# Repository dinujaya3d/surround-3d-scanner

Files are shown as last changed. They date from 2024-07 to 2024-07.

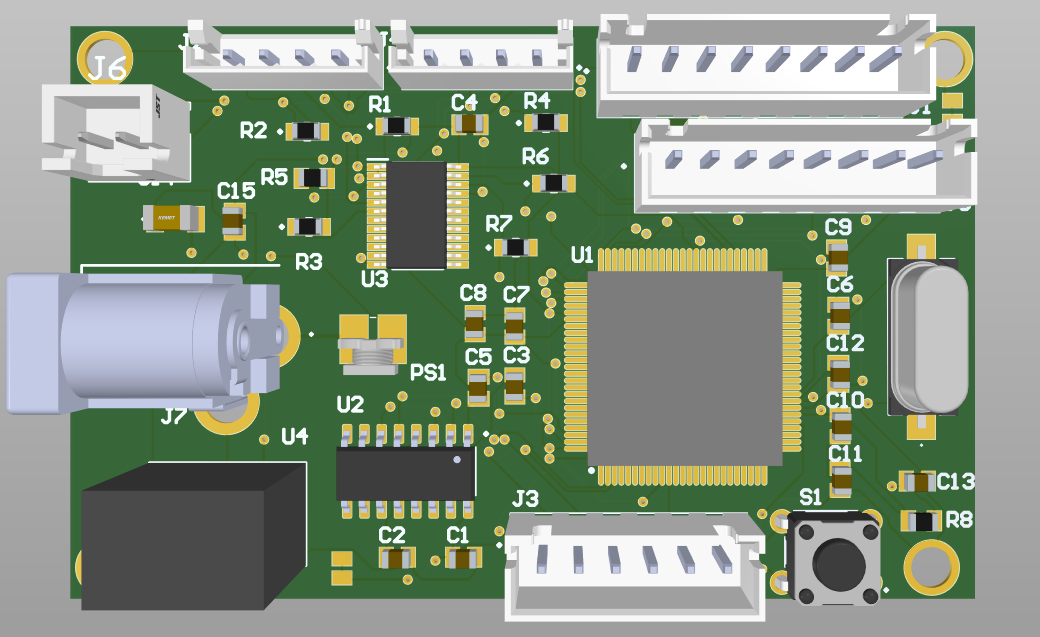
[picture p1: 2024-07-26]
PCB design/3D view.png

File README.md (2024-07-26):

# 3D-Mapper 
* 3D-Mapper is a 3D plotting device made for short-range object detection powered by [ATmega 2560](https://github.com/LasithaAmarasinghe/3D-Mapper/blob/main/data%20sheets/ATMEGA2560.PDF).
* This is developed for the semester 4 project under EN 2160: Electronic Design Realization.



## Working Principle 

* This device measures distances to objects using two Time-of-Flight (TOF) sensors, which are rotated by two stepper motors to cover the entire 3D environment.
* The distance values are saved in (r, theta, alpha) coordinates and then converted to (x, y, z) coordinates.
* Using the [PyVista](https://github.com/pyvista) library in Python, a 3D point cloud is generated from these cartesian coordinates. 
* A tetrahedral mesh is created by performing [3D Delaunay triangulation](https://github.com/LasithaAmarasinghe/3D-Mapper/blob/main/3D%20Delaunay%20Triangulation.pdf) on the point cloud.
* Then the outer surface of this tetrahedral mesh is extracted to form a surface mesh.

## Why "3D-Mapper"?

* Precision in Short-Range Mapping
* Comprehensive Coverage
* Cost-Effective
* Scalability and Customization
* Versatility Across Industries

## Areas of Opportunity

* Emerging Technology Integration - Enhance capabilities with AI and machine learning.
* Market Expansion - Adapt for use in virtual reality (VR) & augmented reality (AR) to access new and growing markets.
* Data Analytics Enhancement - Develop advanced software for better data analysis and visualization, adding value and creating new revenue streams.

## Hardware Specifications

* [ATmega2560](https://github.com/LasithaAmarasinghe/3D-Mapper/blob/main/data%20sheets/ATMEGA2560.PDF)
* [CH340C USB to Serial Chip](https://github.com/LasithaAmarasinghe/3D-Mapper/blob/main/data%20sheets/CH340C%20USB%20to%20serial%20chip.PDF)
* [I2C Multiplexer](https://github.com/LasithaAmarasinghe/3D-Mapper/blob/main/data%20sheets/tca9548a%20I2C%20multiplexer.pdf)
* [Nema 17 Stepper Motors](https://github.com/LasithaAmarasinghe/3D-Mapper/blob/main/data%20sheets/NEMA17%20Stepper%20Motor.PDF)
* [Micro Step Motor Drivers](https://github.com/LasithaAmarasinghe/3D-Mapper/blob/main/data%20sheets/TB6600-Micro%20Step%20Stepper-Motor-Driver.pdf)
* [TOF Sensors](https://github.com/LasithaAmarasinghe/3D-Mapper/blob/main/data%20sheets/TOF.png)
* [12V to 5V Buck Converter](https://github.com/LasithaAmarasinghe/3D-Mapper/blob/main/data%20sheets/R_78CK_0_5-DC_DC%20Converter.pdf)

## Software Specifications

* Arduino IDE
* Solid Works
* Altium
* Python 











## PCB Design



## PCB 

PCB

## Solidworks Design

solidworks
Interior Design
Side view

## Team

team

## For More Information  

- **[Design Document](Design_Document.pdf)**
- **[Design Methodology Report](Design_Methodology_Report.pdf)**

## License
 
 * This project is licensed under the MIT License. See the [LICENSE](MIT-LICENSE.txt) file for details.

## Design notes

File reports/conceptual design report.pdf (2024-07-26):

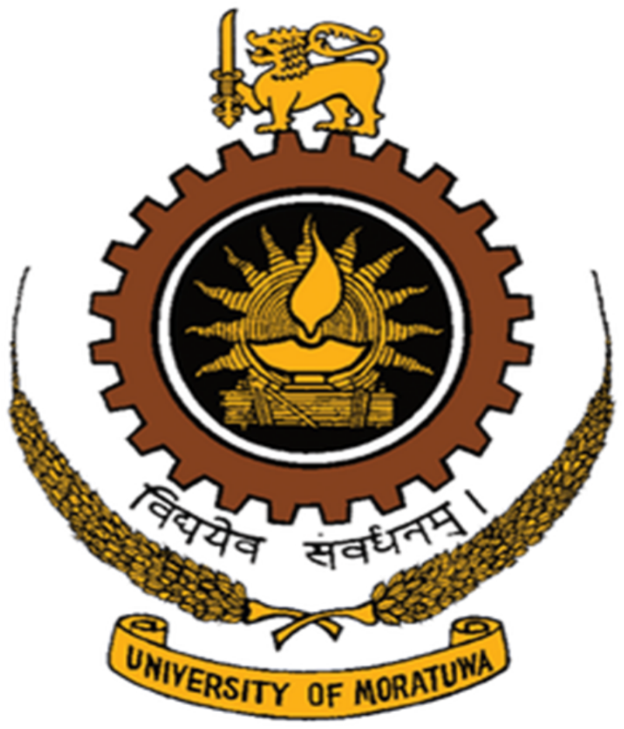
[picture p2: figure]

# Department of Electronic & Telecommunication

Engineering,
University of Moratuwa, Sri Lanka.

# 3D Mapping Device for Object Tracking Conceptual Design Report - Group B

## Submitted By:

210728C Wijewickrama W.K.D.D.D. 210031H Amarasinghe A.A.W.L.R.

Submitted in partial fulfillment of the requirements for the module

# EN 2160 : Electronic Design Realization

7th March 2024

EN2160 | Conceptual Design Report : Group B

## Contents

1 Conceptual Designs and Functional Block Diagrams | 2
2 Comparison of Designs | 8
3 Evaluation Criteria | 9

1

## 1 Conceptual Designs and Functional Block Diagrams

### 1.1 Design 1

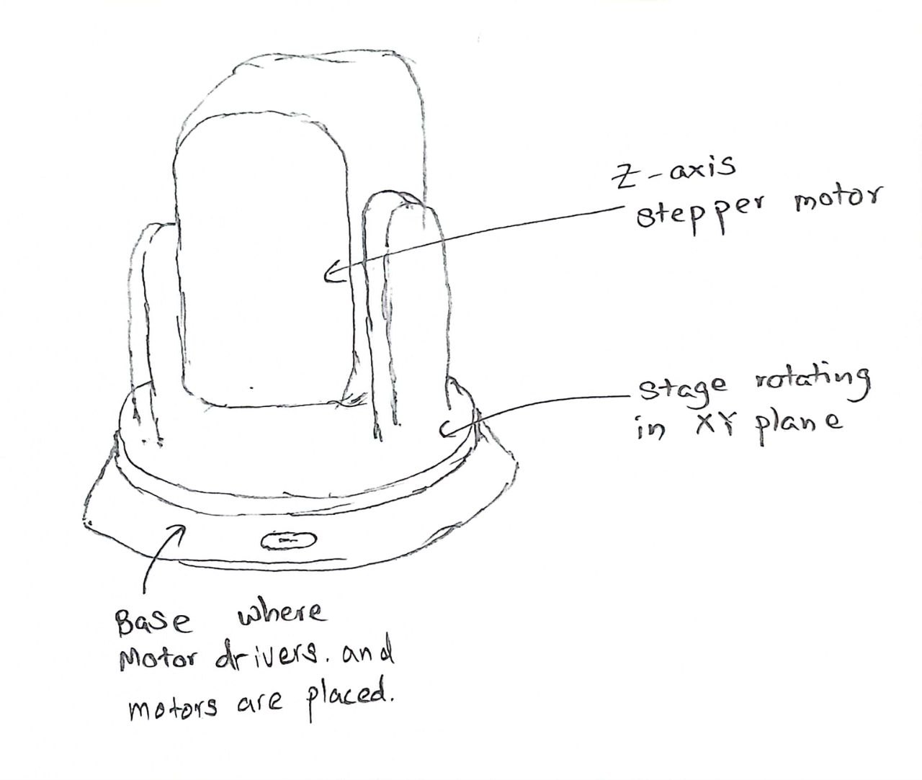
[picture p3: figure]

Figure 1: Design 1: Stage and 2 Steppers

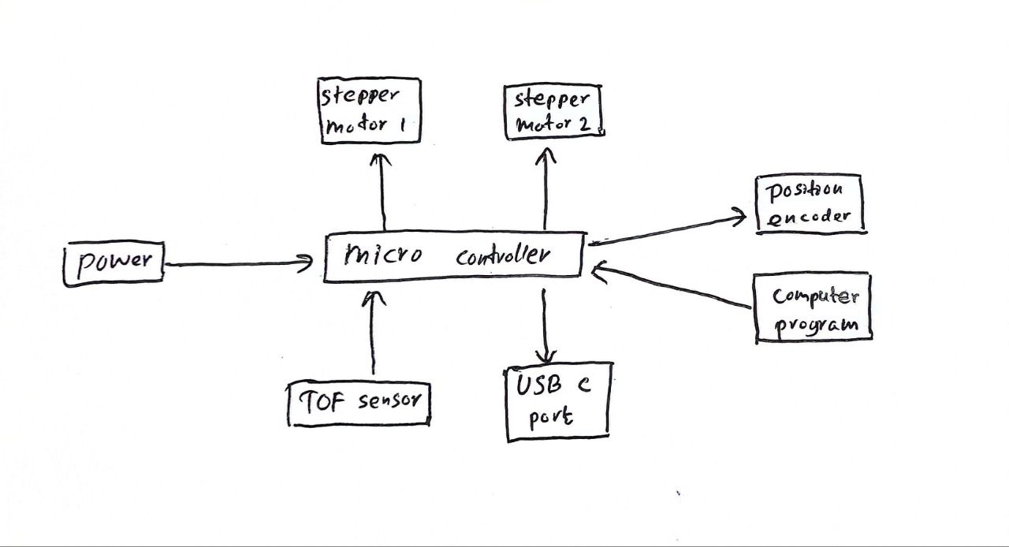
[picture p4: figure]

Figure 2: Block Diagram 1

2

### 1.1.1 Overview

This innovative design merges the Time of Flight (ToF) sensor concept with the precision control of stepper motors to create a dynamic two Degrees of Freedom (2-DoF) rotational system. It incorporates two stepper motors, with one strategically positioned to govern movement along the xy plane within the base, while the other orchestrates stage rotation using z-axis angles obtained from the ToF sensor. This arrangement ensures meticulous measurement of r, θ, and α values for each reading, thereby enhancing system accuracy.

### 1.1.2 Operation

- Integration of ToF sensor technology with stepper motors for precise control.
- Two stepper motors utilized: one for xy plane movement and another for stage rotation.
- ToF sensor provides z-axis angles for enhanced control and accuracy.
- Enables meticulous measurement of r, θ, and α values for each reading.
- Data transmission facilitated through USB Type-C port, ensuring seamless connectivity and efficient data transfer.
- Advanced processing techniques applied on the computer to convert data into a comprehensive point cloud representation.
- Sophisticated image detection algorithms employed for in-depth analysis and interpretation.

### 1.1.3 Advantages

- This design offers precise control over rotational movements.
- Streamlines data processing and analysis, making it a versatile solution for diverse applications requiring precise spatial measurements and analysis.

### 1.1.4 Challenges

However, there are some challenges associated with this design:

- Mechanical Complexity: Incorporating two stepper motors and a ToF sensor system adds mechanical complexity, requiring careful calibration and maintenance to ensure reliable operation.
- Computational Requirements: Advanced processing techniques and image detection algorithms may demand significant computational power, posing challenges in terms of hardware requirements and computational efficiency.

3

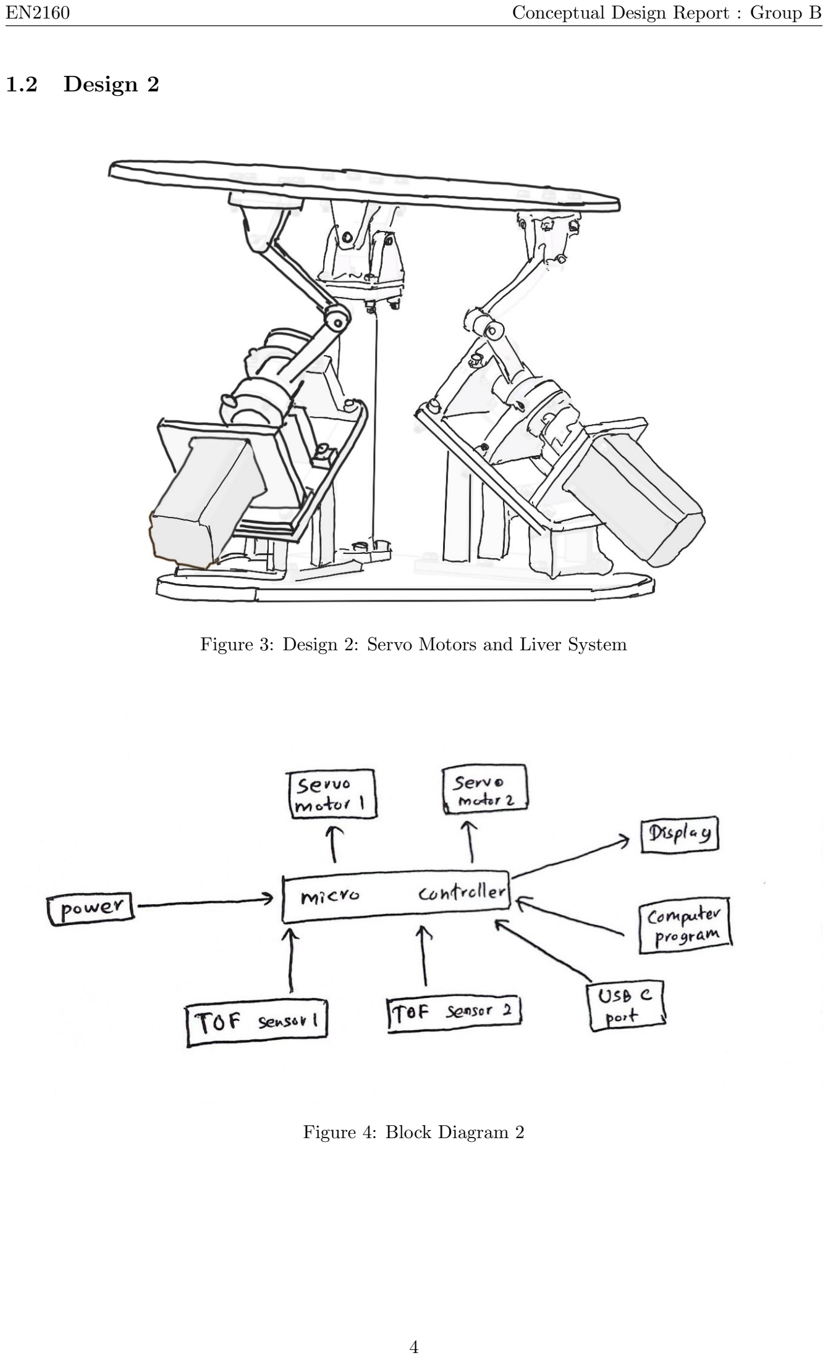
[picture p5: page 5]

### 1.2 Design 2

Figure 3: Design 2: Servo Motors and Liver System

Figure 4: Block Diagram 2

4

### 1.2.1 Overview:

Design 1 utilizes a basement housing two time-of-flight (ToF) sensors, each equipped with servo motors for precise adjustment. The servo motors enable the rotation and tilting of the basement to capture surrounding data from various angles.
Components:
1. Basement Housing: The basement serves as the platform for mounting the ToF sensors and servo motors. It is designed to be adjustable in both rotation and tilt angles.
2. ToF Sensors: Two ToF sensors are mounted on the basement to capture depth information. These sensors emit infrared light pulses and measure the time taken for the pulses to reflect back, allowing for accurate distance calculations.
3. Servo Motors: The servo motors are responsible for adjusting the orientation of the basement. They provide precise control over the rotation and tilt angles, allowing for comprehensive coverage of the surrounding environment.

### 1.2.2 Operation:

- Rotation Control: One servo motor is dedicated to controlling the rotation of the basement. By rotating the basement, the sensors can scan the surroundings horizontally, providing a panoramic view of the scene.
- Tilt Control: The second servo motor adjusts the tilt angle of the basement. This enables the sensors to capture data from different elevations, facilitating a more detailed representation of the environment.

### 1.2.3 Advantages:

- Precise Control: The servo motors offer precise adjustment capabilities, allowing for finetuning of the sensor positions to capture accurate data.
- Comprehensive Coverage: By rotating and tilting the basement, the design ensures thorough coverage of the surrounding environment, resulting in more comprehensive 3D scans.

### 1.2.4 Challenges:

- Mechanical Complexity: The incorporation of servo motors adds mechanical complexity to the design, requiring careful calibration and maintenance to ensure reliable operation.
- Power Consumption: Servo motors may consume significant power, which could impact the overall energy efficiency of the system.

5

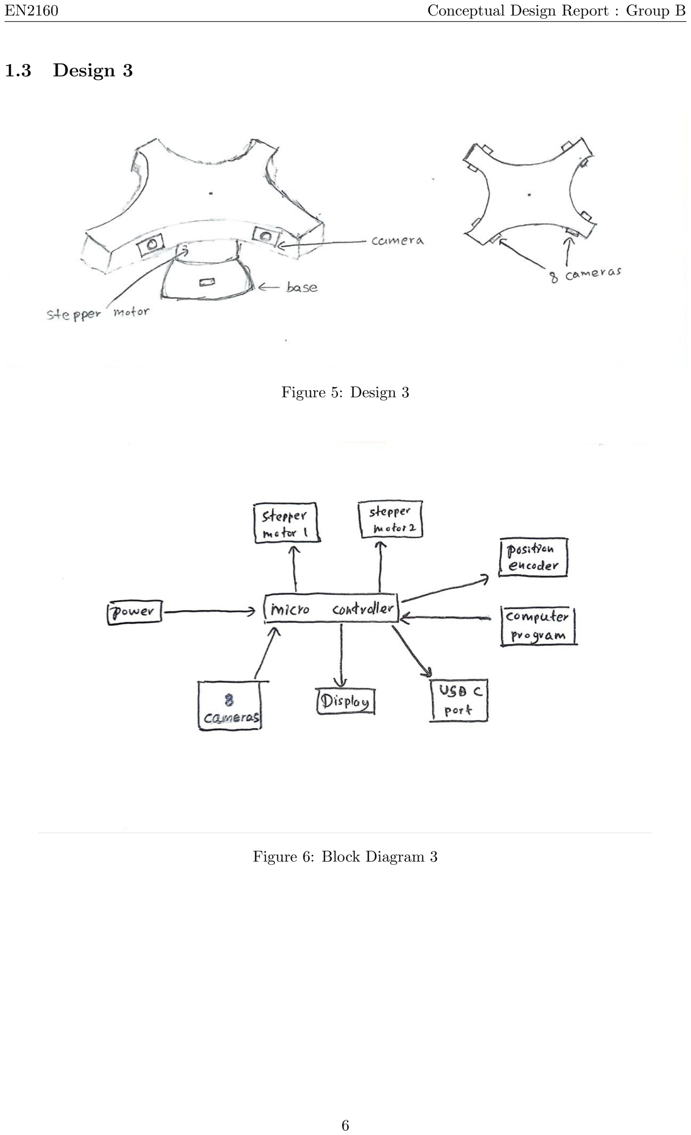
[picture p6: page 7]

### 1.3 Design 3

Figure 5: Design 3

Figure 6: Block Diagram 3

6

### 1.3.1 Overview

This cutting-edge design leverages image processing technology, employing a sophisticated array of eight cameras strategically positioned to capture comprehensive visual data. Among these cameras, a subset is dedicated to recording videos from one side, utilizing precise angles and calibration to facilitate the generation of detailed 3D objects through advanced image processing concepts. The collective data captured by the eight cameras is then meticulously processed through Convolutional Neural Networks (CNNs), enabling the generation of accurate 3D mappings and point clouds.

- Utilization of eight cameras for comprehensive visual data capture.
- Subset of cameras dedicated to video recording from one side.
- Angled and calibrated cameras facilitate detailed 3D object generation.
- Data from the camera array processed through Convolutional Neural Networks (CNNs).
- CNNs enable accurate generation of 3D mappings and point clouds.

### 1.3.2 Challenges

However, a notable challenge lies in the associated costs and computational requirements. The complexity of processing data from multiple cameras in real-time demands significant computational power, which may pose challenges in terms of both hardware affordability and computational efficiency.

### 1.3.3 Advantages

The advantages of this design include:

- High-Quality Data: The use of eight cameras allows for comprehensive visual data capture, resulting in high-quality 3D reconstructions.
- Detailed 3D Objects: The subset of cameras dedicated to video recording from one side, along with precise angles and calibration, facilitates the generation of detailed 3D objects.
- Accurate Processing: The utilization of Convolutional Neural Networks (CNNs) ensures accurate processing of the captured data, leading to precise 3D mappings and point clouds.

### 1.3.4 Significance

This design represents a powerful fusion of cutting-edge imaging technology and advanced computational algorithms, promising high-fidelity 3D reconstructions and data analysis. Despite the challenges posed by cost and computational demands, the potential applications of such a system in various fields such as robotics, augmented reality, and medical imaging underscore its significance and potential impact.

7

## 2 Comparison of Designs

Table 1: Comparison of Designs

Criteria | Design 1 Design 2 Design 3

## Features

## Enclosure Design Criteria Comparison

## Functional Block Design Criteria Comparison

Total | 120 100 105
TOF sensor | ✓ | ✓
cameras | | | ✓
servo motors | | ✓
stepper motors | ✓ | | ✓
display | | ✓ | ✓
position encoder | ✓ | | ✓
Functionality | 8 | 7 | 8
Aesthetics | 9 | 8 | 6
Heat Dissipation | 9 | 8 | 9
Assembly and Serviceability | 8 | 7 | 6
Ergonomics | 9 | 9 | 7
Simplicity | 9 | 5 | 7
Durability | 9 | 7 | 6
Functionality | 8 | 7 | 8
User Experience | 9 | 8 | 7
Manufacturing Feasibility | 9 | 6 | 9
Cost Efficiency | 8 | 6 | 9
Performance | 8 | 7 | 8
Future Proofing | 9 | 8 | 9
Power | 8 | 7 | 6

8

## 3 Evaluation Criteria

### 3.1 Enclosure Design Criteria:

1. Functionality: How well the design supports the main functionalities?
2. Aesthetics: How eye-catching is the design and what is the overall appeal to the user?
3. Heat Dissipation: How much heat is generated and how well has it been managed?
4. Assembly and Serviceability: How easily can the assembly and disassembly be done?
5. Ergonomics: How well does the design fit in the user’s hand and allow easy interaction?
6. Durability: How well does the design withstand impacts and environmental conditions?
7. Simplicity: How simple is the design?

### 3.2 Functional Block Diagram Criteria:

1. Functionality: How well does the circuit design meet functional requirements?
2. User Experience: How intuitive and user-friendly is the interaction?
3. Manufacturing Feasibility: Evaluate the feasibility of manufacturing the design.
4. Cost: Evaluate the overall cost-effectiveness for the provided functionality.
5. Performance: Evaluate signal quality, resolution, and bandwidth range.
6. Future Proofing: To what extent does the design allow for easy replacement or upgrade of individual components?
7. Power Efficiency: How effectively does the device manage power consumption?

9

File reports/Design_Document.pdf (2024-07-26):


# Department of Electronic & Telecommunication

Engineering,
University of Moratuwa, Sri Lanka.

# 3D Mapping Device for Object Tracking Design Documentation - Group B

## Submitted By:

210728C Wijewickrama W.K.D.D.D. 210031H Amarasinghe A.A.W.L.R.

Submitted in partial fulfillment of the requirements for the module

# EN 2160 : Electronic Design Realization

20th June 2024

EN2160 | Design Documentation : Group B

## Contents

1 Introduction | 2
2 Component Selection and Justifications | 2
3 Setting Up Environment | 8
4 Daily Progress | 9

1

## 1 Introduction

The 3D Scanner device represents a cutting-edge solution for precise and efficient three-dimensional data acquisition in various applications. This design document comprehensively outlines the component selection process and daily progress of the project. It encapsulates the combined work of our multi-disciplinary team, leveraging expertise in optical engineering, electronics, software development, and human-centered design principles.
The device features a Time-of-Flight (ToF) sensor designed for precise measurement of distances and angles. It utilizes UART communication via ATMEGA 2560 microcontroller pins connected to a USB-to-Serial converter, enabling seamless interfacing with computers equipped with USB ports for data transmission and visualization. This setup ensures efficient handling of distance measurement data and robust communication capabilities, making the device suitable for applications requiring accurate spatial data acquisition and analysis

## 2 Component Selection and Justifications

### 2.1 Microcontroller Selection

ATMEGA 2560 MCU
The ATMEGA 2560 microcontroller unit (MCU) was selected as the central processing unit for the 3D surround scanner. This microcontroller was chosen for its adequate memory, processing speed, and overall reliability.

Specifications:

- High Performance, Low Power AVR® 8-Bit Microcontroller
- Advanced RISC Architecture
- Non-volatile Program and Data Memories
- JTAG (IEEE std. 1149.1 compliant) Interface
- 51/86 Programmable I/O Lines
- Temperature Range: -40°C to 85°C Industrial

Key Features:

- Memory: The ATMEGA 2560 offers 256 KB of Flash memory, 8 KB of SRAM, and 4 KB of EEPROM, providing sufficient space for handling the initial stages of data processing.
- Processing Speed: It operates at a clock speed of 16 MHz, which meets the demands of real-time data collection and processing required for the 3D mapper.
- Reliability: Known for its stable performance, the ATMEGA 2560 is widely used in various applications, making it a dependable choice for our project.

Reasons for Selection:

- Versatility: The ATMEGA 2560 supports a wide range of peripherals and interfaces, making it adaptable to various components used in the 3D mapper project.
- Community Support: The ATMEGA 2560 has extensive documentation and a large community of users, providing valuable resources and support for troubleshooting and development.

2

- Cost-Effective: Compared to other microcontrollers with similar capabilities, the ATMEGA 2560 offers a good balance between performance and cost, making it an economical choice for the project.
- Ease of Programming: The microcontroller is compatible with the Arduino platform, which simplifies programming and prototyping, allowing for faster development cycles.
- Proven Track Record: The ATMEGA 2560 has been used in numerous successful projects, indicating its reliability and robustness in real-world applications.

Despite these advantages, the memory capacity of the ATMEGA 2560 was insufficient to store the entire dataset generated during the scanning process. Therefore, the data readings had to be transmitted incrementally to a connected computer for further processing and storage.

### 2.2 Time-of-Flight (ToF) Sensors

VL53L0 ToF Sensors
Two Time-of-Flight sensors were selected for the 3D mapper to measure the distance of objects with high precision and speed.

Specifications

- VDD: Regulated 2.8 V output. Almost 150 mA available to power external components.
- VIN: The main 2.6 V to 5.5 V power supply connection. The SCL and SDA level shifters pull the I2C wire high to this level.
- GND: The ground (0 V) connection for power supply. I2C control source must also share a common ground with this board.
- SDA: Level-shifted I2C data line; HIGH is VIN, LOW is 0 V.
- SCL: Level-shifted I2C clock line; HIGH is VIN, LOW is 0 V.
- XSHUT: This pin is an active-low shutdown input; the board pulls it up to VDD to enable the sensor by default.

Reasons for Selection:

- High Precision: ToF sensors are capable of measuring distances accurately, which is crucial for creating a detailed 3D map.
- Speed: These sensors can take measurements rapidly, enabling real-time data collection and processing.
- Range: ToF sensors can cover a sufficient range suitable for the intended mapping application.

3

### 2.3 I2C Multiplexer

I2C Multiplexer
An I2C multiplexer was used to connect the two ToF sensors to the ATMEGA 2560.

Specifications:

- 1-to-8 Bidirectional Translating Switches
- I2C Bus and SMBus Compatible
- Allows Voltage-Level Translation Between 1.8-V, 2.5-V, 3.3-V, and 5-V Buses
- Operating Power-Supply Voltage Range of 1.65-V to 5.5-V
- Low RON Switches

Reasons for Selection:

- Multiple I2C Devices: The multiplexer allows multiple I2C devices to be connected to a single I2C bus, expanding the number of sensors that can be used simultaneously.
- Simplifies Wiring: Reduces the complexity of wiring by allowing easy addition of sensors without requiring additional I2C ports on the microcontroller.
- Efficient Communication: Ensures efficient communication between the microcontroller and the sensors, maintaining the integrity and speed of data transfer.

### 2.4 USB Serial Communication

CH340C Chip
The CH340C chip was chosen for USB serial communication between the ATMEGA 2560 and the connected computer.

Specifications:

- Full-speed USB device interface, compatible with USB V2.0
- Fully compatible with serial port applications
- Supports common MODEM contact signals
- Provides RS232, RS485, RS422 interfaces
- Supports 5V and 3.3V power supply voltages

Reasons for Selection:

- Reliable Communication: Provides a reliable interface for serial communication over USB, essential for transmitting data to the computer for further processing.
- Compatibility: Compatible with a wide range of operating systems, ensuring ease of integration and use.
- Cost-Effective: The CH340C is a cost-effective solution for USB to serial conversion, making it an economical choice for the project.

4

### 2.5 Stepper Motor

Nema17
The NEMA 17 stepper motor is renowned for its versatility and reliability in various applications requiring precise motion control

Specifications

- Holding Torque: 0.35 Nm at continuous current, 0.5 Nm at peak current.
- Continuous Output Current: 1.8 A.
- Step Angle: 1.8°.
- Rotor Inertia: 57 g·cm².
- Weight: 0.37 kg.

Reasons for Selection

1. Compact Size: Suitable for applications with limited space, such as 3D printers and small CNC machines.
2. Moderate Torque: Provides adequate torque (0.35 Nm continuous, 0.5 Nm peak) for precise motion control and handling moderate loads.
3. Precise Control: 1.8° step angle and high subdivision accuracy (1–32 steps) enable fine resolution and accurate positioning.
4. Versatility: Compatible with various driver modules and control systems, offering flexibility in design and integration.
5. Cost-Effectiveness: Balances performance and cost effectively, making it a practical choice for both industrial and DIY projects.
6. Reliability: Known for robust construction and durability, ensuring reliable performance in demanding environments.
7. Availability: Widely available from multiple manufacturers, providing easy access to parts and support.

### 2.6 Stepper Motor Driver

TB6600
The TB6600 stepper motor driver is a versatile choice for controlling stepper motors in various applications. It offers a range of features suitable for precise and powerful motor control, making it ideal for both industrial and DIY projects.

Specifications:

- Model: TB6600
- Compatible Motors: Nema 17/23/34 (42/57/86 Stepper Motor)
- Control Signal: 3.3VDC–24VDC
- Subdivision Accuracy: 1–32
- Output Current: 4A
- Voltage: 9VDC–40VDC

5

Reasons for Selection:

- Motor Compatibility: Compatible with Nema 17, 23, 34 motors.
- Output Current: Up to 4A for sufficient torque.
- Voltage Range: Supports 9VDC–40VDC for flexible power options.
- Subdivision Accuracy: Precision from 1–32 steps.
- Control Signal: Compatible with 3.3VDC–24VDC signals.
- Reliability: Known for robust performance in industrial applications.

### 2.7 Power Step-Down

R-78CK-0.5 12V-5V
A 12V-5V power step-down module was used to supply power to the ATMEGA 2560 and other components.

Specifications

- Efficiency up to 96%
- Pin-out compatible with LM78xx linears
- Compact package
- Wide input range (5V - 40V)
- Short circuit protection, thermal shutdown
- Low ripple and noise

Reasons for Selection:

- Voltage Regulation: Ensures stable voltage supply to the microcontroller and sensors, which is crucial for reliable operation.
- Efficiency: High efficiency in converting 12V input to 5V output, minimizing power loss and heat generation.
- Compact Size: The module is compact, making it easy to integrate into the overall design without adding significant bulk.

### 2.8 Clock Oscillator

### 16 MHz Crystal Oscillator

A 16 MHz crystal oscillator was used to provide the clock signal for the ATMEGA 2560.

Reasons for Selection:

- Precision Timing: Provides a stable and precise clock signal necessary for the accurate operation of the microcontroller.
- Frequency Stability: Ensures consistent performance of the microcontroller by maintaining a stable clock frequency.
- Compatibility: Specifically chosen to match the operational requirements of the ATMEGA 2560.

6

### 2.9 Decoupling Capacitors

100µF Decoupling Capacitors
100µF decoupling capacitors were used to stabilize the power supply to the microcontroller and other components.

Reasons for Selection:

- Noise Reduction: Help to filter out noise and prevent voltage spikes, ensuring a stable power supply.
- Improved Performance: Enhances the overall performance and reliability of the microcontroller by maintaining a clean power signal.
- Protection: Protects sensitive components from transient voltage fluctuations.

### 2.10 Pull-up Resistors

2.2k Resistors
2.2k resistors were used in the I2C lines to ensure proper signal levels.

Reasons for Selection:

- Pull-up Function: These resistors act as pull-up resistors for the I2C bus, ensuring that the lines are correctly biased and that signals are accurately interpreted.
- Signal Integrity: Maintains the integrity of the I2C signals, preventing erroneous data transmission.
- Standard Value: 2.2k ohms is a standard value for pull-up resistors in I2C communication, ensuring compatibility and reliable operation.

7

## 3 Setting Up Environment

### 3.1 Components

ToF Sensor

A Time-of-Flight sensor to measure distance and angles.

UART Communication Interface

UART pins on the ATMEGA 2560 connected to a USB-to-Serial converter (e.g., FTDI or CP2102) to interface with the computer.

Computer

A computer with USB ports to receive data from the microcontroller and perform visualization.

### 3.2 Software Requirements

Python

Install Python 3.10.1 or later on your computer.

PySerial

A Python library to handle serial communication. Installation: pip install pyserial

Matplotlib

A Python library for creating static, animated, and interactive visualizations. Installation: pip install matplotlib

NumPy

A Python library for numerical operations. Installation: pip install numpy

3D Visualization Libraries

Matplotlib supports 3D plotting via mpl toolkits.mplot3d. Installation: pip install matplotlib (already mentioned)

8

## 4 Daily Progress

### 4.1 Distance Measurement using TOF sensor (4 - 10 March 2024)

### 4.1.1 Arduino Code

1 | # include <Wire .h>
2 | # include < Adafruit_VL53L0X .h>

3
4 Adafruit_VL53L0X lox = Adafruit_VL53L0X () ;

5
6 | void setup () {
7 | Serial . begin (115200) ;

8
9 | if (! lox . begin () ) {
10 | Serial . println (F(" Failed to boot VL53L0X "));
11 | while (1) ;
12 | }

13
14 | Serial . println (F(" VL53L0X test "));
15 | }

16
17 | void loop () {
18 | VL53L0X_RangingMeasurementData_t measure ;

19
20 | lox . rangingTest (& measure , false ) ;

21
22 | if ( measure . RangeStatus != 4) { | // phase failures have incorrect data
23 | Serial . print (F(" Distance (mm): ") );
24 | Serial . println ( measure . RangeMilliMeter );
25 | } else {
26 | Serial . println (F("Out of range ")) ;
27 | }

28
29 | delay (100) ;
30 | }

Listing 1: Arduino Code for VL53L0X Sensor

### 4.1.2 Code Explanation

Include Libraries

- #include <Wire.h>

– Wire.h: Library to communicate with I2C devices.

- #include <Adafruit VL53L0X.h>

– Adafruit VL53L0X.h: Library specific to the Adafruit VL53L0X sensor.

Create Sensor Object

- Adafruit VL53L0X lox = Adafruit VL53L0X();

– Creates an instance of the VL53L0X sensor named lox.

9

Setup Function

1 | void setup () {
2 | Serial . begin (115200) ;

3
4 | if (! lox . begin () ) {
5 | Serial . println (F(" Failed to boot VL53L0X "));
6 | while (1) ;
7 | }

8
9 | Serial . println (F(" VL53L0X test "));
10 | }
- Initializes serial communication at 115200 baud.
- Tries to initialize the sensor using lox.begin().
- If the sensor fails to initialize, it prints an error message and enters an infinite loop.
- If initialization is successful, it prints a success message.

Loop Function

1 | void loop () {
2 | VL53L0X_RangingMeasurementData_t measure ;

3
4 | lox . rangingTest (& measure , false ) ;

5
6 | if ( measure . RangeStatus != 4) {
7 | Serial . print (F(" Distance (mm): ") );
8 | Serial . println ( measure . RangeMilliMeter );
9 | } else {
10 | Serial . println (F("Out of range ")) ;
11 | }

12
13 | delay (100) ;
14 | }
- Declares a variable measure of type VL53L0X RangingMeasurementData t to store the measurement data.
- Calls lox.rangingTest(&measure, false) to perform a ranging test and store the result in measure.
- Checks the RangeStatus to determine if the measurement is valid (status not equal to 4).

– If valid, prints the measured distance in millimeters.
– If not valid (out of range), prints an error message.
- Delays for 100 milliseconds before taking another measurement.

10

### 4.2 Stepper Motor Check (11 - 17 March 2024)

### 4.2.1 Arduino Code

1 | # include < AccelStepper .h>
2 | # include <Wire .h>
3 | # include < Adafruit_VL53L0X .h>

4
5 | // Define stepper motor connections
6 | # define STEP_PIN 10
7 | # define DIR_PIN 11

8
9 | # define STEP_PIN_2 12
10 | # define DIR_PIN_2 13

11
12 | # define STEPS_PER_REVOLUTION 200
13 | # define ANGLE_INCREMENT 1.8

14
15 | // Create a stepper object
16 | AccelStepper stepper ( AccelStepper :: DRIVER , STEP_PIN , DIR_PIN );
17 | AccelStepper stepper2 ( AccelStepper :: DRIVER , STEP_PIN_2 , DIR_PIN_2 );

18
19 | void setup () {
20 | // Set up the speed and acceleration of the stepper motor
21 | stepper . setMaxSpeed (1000) ;
22 | stepper . setAcceleration (500) ;

23
24 | stepper2 . setMaxSpeed (1000) ;
25 | stepper2 . setAcceleration (500) ;

26
27 | // Set the motor to run continuously
28 | stepper . moveTo (0) ;
29 | stepper2 . moveTo (0) ;
30 | }

31
32 | void loop () {
33 | // Run the stepper motor
34 | stepper . run () ;
35 | stepper2 . run () ;
36 | }

Listing 2: Arduino Code for Two Stepper Motors with AccelStepper

### 4.2.2 Code Explanation

Include Libraries

- #include <AccelStepper.h>

– AccelStepper.h: Library for controlling stepper motors.

- #include <Wire.h>

– Wire.h: Library to communicate with I2C devices.

- #include <Adafruit VL53L0X.h>

– Adafruit VL53L0X.h: Library specific to the Adafruit VL53L0X sensor.

11

Define Stepper Motor Connections

1 | \ item \ texttt {\# define STEP_PIN 10}
2 | \ item \ texttt {\# define DIR_PIN 11}
- Defines the step and direction pins for the first stepper motor.
1 | \ item \ texttt {\# define STEP_PIN \_2 12}
2 | \ item \ texttt {\# define DIR_PIN \_2 13}
- Defines the step and direction pins for the second stepper motor.
1 | \ item \ texttt {\# define STEPS \ _PER \ _REVOLUTION 200}
2 | \ item \ texttt {\# define ANGLE \ _INCREMENT 1.8}
- Defines the number of steps per revolution and the angle increment.

Create Stepper Objects

1 AccelStepper stepper ( AccelStepper :: DRIVER , STEP_PIN , DIR_PIN );

- Creates an instance of the AccelStepper class for the first stepper motor.

1 AccelStepper stepper2 ( AccelStepper :: DRIVER , STEP_PIN \_2 , DIR_PIN \ _2 );

- Creates an instance of the AccelStepper class for the second stepper motor.

Setup Function

1 | void setup () {
2 | stepper . setMaxSpeed (1000) ;
3 | stepper . setAcceleration (500) ;

4
5 | stepper2 . setMaxSpeed (1000) ;
6 | stepper2 . setAcceleration (500) ;

7
8 | stepper . moveTo (0) ;
9 | stepper2 . moveTo (0) ;
10 | }
- void setup()

– Initializes the setup function.

- stepper.setMaxSpeed(1000);

– Sets the maximum speed for the first stepper motor.

- stepper.setAcceleration(500);

– Sets the acceleration for the first stepper motor.

- stepper2.setMaxSpeed(1000);

– Sets the maximum speed for the second stepper motor.

12

- stepper2.setAcceleration(500);

– Sets the acceleration for the second stepper motor.

- stepper.moveTo(0);

– Moves the first stepper motor to position 0.

- stepper2.moveTo(0);

– Moves the second stepper motor to position 0.

Loop Function

1 | void loop () {
2 | stepper . run () ;
3 | stepper2 . run () ;
4 | }
- void loop()

– Initializes the loop function.

- stepper.run();

– Runs the first stepper motor.

- stepper2.run();

– Runs the second stepper motor.

13

4.3 3D Cloud Generation (18 - 24 March 2024)

### 4.3.1 Python Code

import ast
import numpy as np
import pyvista as pv

# Open the file in read mode

with open (’example . txt ’, ’r’) as file : # Read the file content
content = file . read ()

# Use ast . literal_eval to convert the string to a 2D list points = np . array ( ast . literal_eval ( content ))

# Create a PolyData object

cloud = pv . PolyData ( points )

# Plot the point cloud

cloud . plot ()

# Create a 3D Delaunay triangulation of the point cloud volume = cloud . delaunay_3d ( alpha =0.6)

# Extract the outer surface of the volume

shell = volume . extract_geometry ()

# Plot the resulting mesh

shell . plot ()

Listing 3: Python Code for 3D Delaunay Triangulation

### 4.3.2 Code Explanation

### 4.3.3 Import Libraries

- import ast

– ast: Library for safely evaluating strings containing Python expressions.

- import numpy as np

– numpy: Library for numerical operations on arrays.

- import pyvista as pv

– pyvista: Library for 3D plotting and mesh analysis.

Open and Read File

with open (’example . txt ’, ’r’) as file : content = file . read ()

- Opens the file ’example.txt’ in read mode and reads its content.

Convert String to 2D List

points = np . array ( ast . literal_eval ( content ))

- Safely evaluates the string content and convert it into a 2D list.
- Converts the 2D list to a NumPy array for further processing.

14

Create PolyData Object

1 cloud = pv . PolyData ( points )

- Creates a PolyData object from the points array using PyVista.

Plot the Point Cloud

1 cloud . plot ()

- Plots the point cloud using PyVista.

Create 3D Delaunay Triangulation

1 volume = cloud . delaunay_3d ( alpha =0.6)

- Creates a 3D Delaunay triangulation of the point cloud with an alpha value of 0.6.

Extract Outer Surface

1 shell = volume . extract_geometry ()

- Extracts the outer surface of the triangulated volume.

Plot the Resulting Mesh

1 shell . plot ()

- Plots the resulting mesh of the outer surface using PyVista.

15

4.4 2D Scan (25 - 31 March 2024)

### 4.4.1 Arduino Code

1 | # include <Wire .h>
2 | # include < Adafruit_VL53L0X .h>
3 | # include <Arduino .h>
4 | # include " A4988 .h"

5
6 | # define STEPS_PER_REVOLUTION 200
7 | # define ANGLE_INCREMENT 1.8

8
9 | int Step = 10; // GPIO14 ---D5 of Nodemcu -- Step of stepper motor driver
10 | int Dire | = 11; // GPIO2 ---D4 of Nodemcu -- Direction of stepper motor driver
11 | int Sleep = 14; // GPIO12 ---D6 of Nodemcu - Control Sleep Mode on A4988
12 | int MS1 = 13; // GPIO13 - --D7 of Nodemcu - -MS1 for A4988
13 | int MS2 = 16; // GPIO16 - --D0 of Nodemcu - -MS2 for A4988
14 | int MS3 = 15; // GPIO15 - --D8 of Nodemcu - -MS3 for A4988

15
16 | // Motor Specs
17 | const int spr = 200; // Steps per revolution
18 | int RPM = 100; // Motor Speed in revolutions per minute
19 | int Microsteps = 1; // Stepsize (1 for full steps , 2 for half steps , 4 for quarter
steps , etc )

20
21 | // Providing parameters for motor control
22 | A4988 stepper ( spr , Dire , Step , MS1 , MS2 , MS3 );

23
24 | Adafruit_VL53L0X lox = Adafruit_VL53L0X () ;
25 | // Stepper stepper ( STEPS_PER_REVOLUTION , 2, 3 , 4 , 5); | // Adjust pin numbers
accordingly

26
27 | const int num_measurements = STEPS_PER_REVOLUTION ;
28 | float measurements [ num_measurements ][2];

29
30 | String arrayToString (int arr [] , int size ) {
31 | | String result = "{";
32 | for (int i = 0; i < size ; i ++) {
33 | result += String ( arr [i ]) ;
34 | | if (i < size - 1) {
35 | | result += ", ";
36 | | }
37 | }
38 | | result += "}";
39 | | return result ;
40 | }

41
42 | void setup () {
43 | | Serial . begin (9600) ;
44 | Serial1 . begin (9600) ; // Use Serial1 for communication on Arduino Mega

45
46 | pinMode ( Step , OUTPUT ); // Step pin as output
47 | pinMode ( Dire , | OUTPUT ); // Direcction pin as output
48 | pinMode ( Sleep , | OUTPUT ) ; // Set Sleep OUTPUT Control button as output
49 | digitalWrite ( Step , LOW ); // Currently no stepper motor movement
50 | | digitalWrite ( Dire , LOW );

51
52 | // Set target motor RPM to and microstepping setting
53 | // stepper . begin (RPM , Microsteps );

54
55 | | if (! lox . begin () ) {
56 | Serial . println (F(" Failed to boot VL53L0X "));
57 | | while (1) ;
58 | }

59
60 | pinMode (13 , OUTPUT ) ; | // Set pin 13 as an output

61
62 | // | stepper . setSpeed (500) ; | // Adjust the speed as needed

16

63
64 | Serial . println (F(" VL53L0X test with Stepper Motor "));
65 | }

66
67 | void loop () {
68 | digitalWrite (12 , HIGH );
69 | digitalWrite ( Sleep , HIGH ) ; //A logic high allows normal operation of the A4988 by
removing from sleep
70 | stepper . rotate (360) ;

71
72 | for (int i = 0; i < num_measurements ; i ++) {
73 | // Rotate stepper motor by ANGLE_INCREMENT degrees
74 | // | stepper . step ( ANGLE_INCREMENT );

75
76 | // Take distance measurement
77 | VL53L0X_RangingMeasurementData_t measure ;
78 | lox . rangingTest (& measure , false ) ;

79
80 | if ( measure . RangeStatus != 4) { | // phase failures have incorrect data
81 | measurements [i ][0] = i * ANGLE_INCREMENT ;
82 | measurements [i ][1] = measure . RangeMilliMeter ;
83 | } else {
84 | measurements [i ][0] = i * ANGLE_INCREMENT ;
85 | measurements [i ][1] = 10000;
86 | }

87
88 | // No delay or minimal delay between steps
89 | }

90
91 | // Print the 2D array after 360 degrees rotation
92 | Serial . print (" aaa [");
93 | for (int i = 0; i < num_measurements ; i ++) {
94 | Serial . print ("[") ;
95 | Serial . print ( measurements [ i ][0]) ;
96 | Serial . print (",") ;
97 | Serial . print ( measurements [ i ][1]) ;
98 | Serial . print ("],");
99 | }
100 | Serial . println ("]");
101 | // Serial . println ( arrayToString ());

102
103 | // Reset the stepper motor to its initial position
104 | // | stepper . step ( -360 * STEPS_PER_REVOLUTION / 360) ;
105 | digitalWrite (13 , LOW );

106
107 | // Delay before starting a new measurement
108 | delay (5000) ;
109 | }

Listing 4: Arduino Code for VL53L0X Sensor with Stepper Motors and A4988 Driver

### 4.4.2 Code Explanation

Import Libraries

- #include <Wire.h>

– Provides I2C communication.

- #include <Adafruit VL53L0X.h>

– Provides functions for the VL53L0X sensor.

- #include <Arduino.h>

– Provides core Arduino functions.

17

- #include "A4988.h"

– Provides functions for controlling the A4988 stepper motor driver.

Define Constants and Variables

- #define STEPS PER REVOLUTION 200

– Defines the number of steps per revolution for the stepper motor.

- #define ANGLE INCREMENT 1.8

– Defines the angle increment for each step.

- int Step = 10;

– Defines the GPIO pin for the step signal.

- int Dire = 11;

– Defines the GPIO pin for the direction signal.

- int Sleep = 14;

– Defines the GPIO pin for the sleep signal.

- int MS1 = 13;

– Defines the GPIO pin for the MS1 signal.

- int MS2 = 16;

– Defines the GPIO pin for the MS2 signal.

- int MS3 = 15;

– Defines the GPIO pin for the MS3 signal.

Motor Specifications and Setup

- const int spr = 200;

– Sets the steps per revolution for the motor.

- int RPM = 100;

– Sets the motor speed in revolutions per minute.

- int Microsteps = 1;

– Sets the microstepping mode.

- A4988 stepper(spr, Dire, Step, MS1, MS2, MS3);

– Initializes the A4988 stepper motor driver.

- Adafruit VL53L0X lox = Adafruit VL53L0X();

– Initializes the VL53L0X sensor.

18

Setup Function

1 | void setup () {
2 | | Serial . begin (9600) ;
3 | Serial1 . begin (9600) ; // Use Serial1 for communication on Arduino Mega

4
5 | pinMode ( Step , OUTPUT ); // Step pin as output
6 | pinMode ( Dire , | OUTPUT ); // Direction pin as output
7 | pinMode ( Sleep , | OUTPUT ) ; // Set Sleep OUTPUT Control button as output
8 | digitalWrite ( Step , LOW ); // Currently no stepper motor movement
9 | | digitalWrite ( Dire , LOW );

10
11 | // Set target motor RPM and microstepping setting
12 | // stepper . begin (RPM , Microsteps );

13
14 | | if (! lox . begin () ) {
15 | Serial . println (F(" Failed to boot VL53L0X "));
16 | | while (1) ;
17 | }

18
19 | pinMode (13 , OUTPUT ) ; | // Set pin 13 as an output

20
21 | // | stepper . setSpeed (500) ; | // Adjust the speed as needed

22
23 | Serial . println (F(" VL53L0X test with Stepper Motor "));
24 | }
- Initializes serial communication.
- Sets pin modes for the stepper motor driver.
- Initializes the VL53L0X sensor.
- Prints a test message to the serial monitor.

Main Loop

1 | void loop () {
2 | digitalWrite (12 , HIGH );
3 | digitalWrite ( Sleep , HIGH ) ; //A logic high allows normal operation of the A4988 by
removing from sleep
4 | stepper . rotate (360) ;

5
6 | for (int i = 0; i < num_measurements ; i ++) {
7 | // Rotate stepper motor by ANGLE_INCREMENT degrees
8 | // | stepper . step ( ANGLE_INCREMENT );

9
10 | // Take distance measurement
11 | VL53L0X_RangingMeasurementData_t measure ;
12 | lox . rangingTest (& measure , false ) ;

13
14 | if ( measure . RangeStatus != 4) { | // phase failures have incorrect data
15 | measurements [i ][0] = i * ANGLE_INCREMENT ;
16 | measurements [i ][1] = measure . RangeMilliMeter ;
17 | } else {
18 | measurements [i ][0] = i * ANGLE_INCREMENT ;
19 | measurements [i ][1] = 10000;
20 | }

21
22 | // No delay or minimal delay between steps
23 | }

24
25 | // Print the 2D array after 360 degrees rotation
26 | Serial . print (" aaa [");
27 | for (int i = 0; i < num_measurements ; i ++) {

19

28 | | Serial . print ("[") ;
29 | | Serial . print ( measurements [ i ][0]) ;
30 | | Serial . print (",") ;
31 | | Serial . print ( measurements [ i ][1]) ;
32 | | Serial . print ("],");
33 | }
34 | | Serial . println ("]");
35 | | // Serial . println ( arrayToString ());

36
37 | | // Reset the stepper motor to its initial position
38 | // | stepper . step ( -360 * STEPS_PER_REVOLUTION / 360) ;
39 | | digitalWrite (13 , LOW );

40
41 | | // Delay before starting a new measurement
42 | | delay (5000) ;
43 | }
- Activates the A4988 driver.
- Rotates the stepper motor 360 degrees.
- Takes distance measurements with the VL53L0X sensor at each step.
- Stores measurements in a 2D array.
- Prints the measurements to the serial monitor in a JSON-like format.
- Resets the stepper motor.
- Delays before starting a new measurement cycle.

20

4.5 3D scan (1 - 7 April 2024)

### 4.5.1 Arduino Code

1 | # include <Wire .h>
2 | # include < Adafruit_VL53L0X .h>

3
4 | # define STEP_PIN_1 8
5 | # define DIR_PIN_1 9
6 | # define ENA_PIN_1 10

7
8 | # define STEP_PIN_2 4
9 | # define DIR_PIN_2 3
10 | # define ENA_PIN_2 2

11
12 | # define XY_REV 200
13 | # define XZ_REV 50

14
15 # define ANGLE_INCREMENT 1.8

16
17 Adafruit_VL53L0X lox = Adafruit_VL53L0X () ;

18
19 float measurements [ XZ_REV ][3];

20
21 | void setup () {
22 | Serial . begin (9600) ; | // Initialize the serial monitor

23
24 | if (! lox . begin () ) {
25 | Serial . println (F(" Failed to boot VL53L0X "));
26 | while (1) ;
27 | }
28 | pinMode (4 , OUTPUT );
29 | pinMode (3 , OUTPUT );
30 | pinMode (2 , OUTPUT );

31
32 | pinMode (7 , OUTPUT );
33 | pinMode (8 , OUTPUT );
34 | pinMode (9 , OUTPUT );

35
36 | digitalWrite ( ENA_PIN_1 , LOW );
37 | digitalWrite ( ENA_PIN_2 , LOW );

38
39 | Serial . println (F(" VL53L0X test with Stepper Motor "));
40 | }

41
42 | void loop () {
43 | // put your main code here , to run repeatedly :
44 | for (int i =0; i < XY_REV ; i ++) {
45 | if (i %2 == 0) {
46 | digitalWrite ( DIR_PIN_2 , HIGH );
47 | } else {
48 | digitalWrite ( DIR_PIN_2 , LOW );
49 | }
50 | for (int j =0; j < XZ_REV ; j ++) {
51 | VL53L0X_RangingMeasurementData_t measure ;
52 | lox . rangingTest (& measure , false ) ;

53
54 | if (i %2 == 0) {
55 | if ( measure . RangeStatus != 4) { | // phase failures have incorrect data
56 | measurements [j ][0] = j * ANGLE_INCREMENT - 45;
57 | measurements [j ][1] = i * ANGLE_INCREMENT ;
58 | measurements [j ][2] = measure . RangeMilliMeter ;
59 | } else {
60 | measurements [j ][0] = j * ANGLE_INCREMENT - 45;
61 | measurements [j ][1] = i * ANGLE_INCREMENT ;
62 | measurements [j ][2] = 10000;
63 | }
64 | } else {

21

65 | if ( measure . RangeStatus != 4) { | // phase failures have incorrect data
66 | measurements [ XZ_REV - j -1][0] = j * ANGLE_INCREMENT - 45;
67 | measurements [ XZ_REV - j - 1][1] = i * ANGLE_INCREMENT ;
68 | measurements [ XZ_REV - j - 1][2] = measure . RangeMilliMeter ;
69 | } else {
70 | measurements [ XZ_REV - j - 1][0] = j * ANGLE_INCREMENT - 45;
71 | measurements [ XZ_REV - j - 1][1] = i * ANGLE_INCREMENT ;
72 | measurements [ XZ_REV - j - 1][2] = 10000;
73 | }
74 | }
75 | digitalWrite ( STEP_PIN_2 , HIGH );
76 | digitalWrite ( STEP_PIN_2 , LOW ) ;
77 | }
78 | Serial . print (" aaa [");
79 | for (int k = 0; k < XZ_REV ; k ++) {
80 | Serial . print ("[") ;
81 | Serial . print ( measurements [ k ][0]) ;
82 | Serial . print (",") ;
83 | Serial . print ( measurements [ k ][1]) ;
84 | Serial . print ("],");
85 | Serial . print ( measurements [ k ][2]) ;
86 | Serial . print ("],");
87 | }
88 | Serial . println ("]");
89 | digitalWrite ( STEP_PIN_1 , HIGH );
90 | digitalWrite ( STEP_PIN_1 , LOW ) ;
91 | }

92
93 }

Listing 5: Arduino Code for VL53L0X Sensor with Stepper Motors

### 4.5.2 Code Explanation

Import Libraries

- #include <Wire.h>

– Provides I2C communication.

- #include <Adafruit VL53L0X.h>

– Provides functions for the VL53L0X sensor.

Define Constants and Variables

- #define STEP PIN 1 8

– Defines the GPIO pin for the step signal of the first stepper motor.

- #define DIR PIN 1 9

– Defines the GPIO pin for the direction signal of the first stepper motor.

- #define ENA PIN 1 10

– Defines the GPIO pin for the enable signal of the first stepper motor.

- #define STEP PIN 2 4

– Defines the GPIO pin for the step signal of the second stepper motor.

- #define DIR PIN 2 3

– Defines the GPIO pin for the direction signal of the second stepper motor.

22

- #define ENA PIN 2 2

– Defines the GPIO pin for the enable signal of the second stepper motor.

- #define XY REV 200

– Defines the number of steps per revolution for the XY plane.

- #define XZ REV 50

– Defines the number of steps per revolution for the XZ plane.

- #define ANGLE INCREMENT 1.8

– Defines the angle increment for each step.

- Adafruit VL53L0X lox = Adafruit VL53L0X();

– Initializes the VL53L0X sensor.

- float measurements[XZ REV][3];

– Initializes a 2D array to store the measurement data.

Setup Function

void setup () {
2 | Serial . begin (9600) ; | // Initialize the serial monitor
| if (! lox . begin () ) {
Serial . println (F(" Failed to boot VL53L0X "));
| while (1) ;
| }
| pinMode (4 , OUTPUT );
| pinMode (3 , OUTPUT );
| pinMode (2 , OUTPUT );
| pinMode (7 , OUTPUT );
| pinMode (8 , OUTPUT );
| pinMode (9 , OUTPUT );

digitalWrite ( ENA_PIN_1 , LOW );
digitalWrite ( ENA_PIN_2 , LOW );

Serial . println (F(" VL53L0X test with Stepper Motor "));

}

- Initializes serial communication.
- Initializes the VL53L0X sensor.
- Sets pin modes for the stepper motor driver.
- Enables the stepper motor drivers.
- Prints a test message to the serial monitor.

23

Main Loop

void loop () {
// put your main code here , to run repeatedly : for (int i =0; i < XY_REV ; i ++) {
if (i %2 == 0) {
digitalWrite ( DIR_PIN_2 , HIGH );
} else {
digitalWrite ( DIR_PIN_2 , LOW );

}
for (int j =0; j < XZ_REV ; j ++) { VL53L0X_RangingMeasurementData_t measure ; lox . rangingTest (& measure , false ) ;

if (i %2 == 0) {
14 | if ( measure . RangeStatus != 4) { | // phase failures have incorrect data
measurements [j ][0] = j * ANGLE_INCREMENT - 45; measurements [j ][1] = i * ANGLE_INCREMENT ; measurements [j ][2] = measure . RangeMilliMeter ;
| } else {
measurements [j ][0] = j * ANGLE_INCREMENT - 45; measurements [j ][1] = i * ANGLE_INCREMENT ;
| measurements [j ][2] = 10000;

}
| } else {
24 | if ( measure . RangeStatus != 4) { | // phase failures have incorrect data
measurements [ XZ_REV - j -1][0] = j * ANGLE_INCREMENT - 45; measurements [ XZ_REV - j - 1][1] = i * ANGLE_INCREMENT ; measurements [ XZ_REV - j - 1][2] = measure . RangeMilliMeter ;
| } else {
measurements [ XZ_REV - j - 1][0] = j * ANGLE_INCREMENT - 45; measurements [ XZ_REV - j - 1][1] = i * ANGLE_INCREMENT ; measurements [ XZ_REV - j - 1][2] = 10000;

}

}
| digitalWrite ( STEP_PIN_2 , HIGH );
| digitalWrite ( STEP_PIN_2 , LOW ) ;

}
| Serial . print (" aaa [");
| for (int k = 0; k < XZ_REV ; k ++) {
| Serial . print ("[") ;
| Serial . print ( measurements [ k ][0]) ;
| Serial . print (",") ;
| Serial . print ( measurements [ k ][1]) ;
| Serial . print ("],");
| Serial . print ( measurements [ k ][2]) ;
| Serial . print ("],");

}
| Serial . println ("]");
| digitalWrite ( STEP_PIN_1 , HIGH );
| digitalWrite ( STEP_PIN_1 , LOW ) ;

}

}

- Runs the main loop repeatedly.
- Controls the direction of the second stepper motor.
- Takes distance measurements with the VL53L0X sensor at each step.
- Stores measurements in a 2D array.
- Prints the measurements to the serial monitor in a JSON-like format.
- Steps the first stepper motor.

24

### 4.6 Serial Communication - Receiver (22 - 28 April 2024)

### 4.6.1 Python Code

1 | import serial
2 | import json
3 | from math import cos , sin , pi
4 | import matplotlib . pyplot as plt
5 | import numpy as np
6 | from mpl_toolkits . mplot3d import Axes3D

7
8 from datetime import datetime

9
10 | # datetime object containing current date and time
11 | now = datetime . now ()

12
13 print (" now =", now )

14
15 | # dd/mm/YY H:M:S
16 | dt_string = now . strftime ("%d/%m/%Y %H:%M:%S")

17
18 printed = False

19
20 | def plot_lines ( coordinates ) :
21 | x_values , y_values = zip (* coordinates )
22 | plt . plot ( x_values , y_values , color =’blue ’, linestyle =’-’, linewidth =2 ,
| label =’Line ’)

23
24 | plt . title (’Graph with Connected Line (No Dots )’)
25 | plt . xlabel (’X- axis ’)
26 | plt . ylabel (’Y- axis ’)

27
28 | # Set axis limits to always be 0 to 300
29 | # plt . xlim (0 , 300)
30 | # plt . ylim (0 , 300)

31
32 | # Set the aspect ratio to be equal
33 | plt . gca () . set_aspect (’equal ’, adjustable =’box ’)

34
35 | plt . grid ( True )
36 | plt . legend ()
37 | plt . show ()

38
39 | def plot_dots ( coordinates ):
40 | x_values , y_values = zip (* coordinates )
41 | plt . scatter ( x_values , y_values , color =’blue ’, marker =’o’)
42 | plt . title (’Graph with Dots ’)
43 | plt . xlabel (’X- axis ’)
44 | plt . ylabel (’Y- axis ’)

45
46 | # plt . xlim (0 , 300)
47 | # plt . ylim (0 , 300)

48
49 | plt . gca () . set_aspect (’equal ’, adjustable =’box ’)

50
51 | plt . grid ( True )
52 | plt . show ()

53

54
55 | def plot_3d_surface ( coordinates ) :
56 | x_coords = [ coordinate [0] for coordinate in coordinates ]
57 | y_coords = [ coordinate [1] for coordinate in coordinates ]
58 | z_coords = [ coordinate [2] for coordinate in coordinates ]

59
60 | # Convert coordinates to numpy arrays
61 | x = np . array ( x_coords )
62 | y = np . array ( y_coords )
63 | z = np . array ( z_coords )

25

64
65 | # Create a 3D plot
66 | fig = plt . figure ()
67 | ax = fig . add_subplot (111 , projection =’3d’)

68
69 | # Plot the scatter plot
70 | ax . scatter (x , y , z , c =’b’, marker =’o’, s = 1)

71
72 | # Connect the points with lines
73 | for i in range (1 , len (x )):
74 | ax . plot ([ x[i -1] , x[ i ]] , [y[i -1] , y[ i ]] , [z[i -1] , z[ i ]] , c=’b’)

75
76 | ax . set_xlabel (’x’)
77 | ax . set_ylabel (’y’)
78 | ax . set_zlabel (’z’)

79
80 | plt . show ()

81
82 | def plot_3d_wireframe ( coordinates ):
83 | x_coords = [ coordinate [0] for coordinate in coordinates ]
84 | y_coords = [ coordinate [1] for coordinate in coordinates ]
85 | z_coords = [ coordinate [2] for coordinate in coordinates ]

86
87 | # Convert coordinates to numpy arrays
88 | x = np . array ( x_coords )
89 | y = np . array ( y_coords )
90 | z = np . array ( z_coords )

91
92 | # Create a 3D plot
93 | fig = plt . figure ()
94 | ax = fig . add_subplot (111 , projection =’3d’)

95
96 | # Plot the wireframe
97 | ax . plot_trisurf (x , y , z , linewidth =0 , antialiased = False )

98
99 | ax . set_xlabel (’x’)
100 | ax . set_ylabel (’y’)
101 | ax . set_zlabel (’z’)

102
103 | plt . show ()

104

105
106 | def str2list ( input_string ):
107 | input_string = input_string . replace (’\r’, "")
108 | input_string = input_string . replace (’\n’, "")

109
110 | temp_buffer = []
111 | temp_text = ’’
112 | selected_dots = []

113
114 | for stringData in input_string . split (’\n’):
115 | temp_buffer . append ( temp_text + stringData . split (’\n’) [0])
116 | temp_text = ’’

117
118 | if temp_buffer [ -1][:3] == " aaa ":
119 | temp_text = ’’
120 | build_temp = temp_buffer [ -1][3:]. rstrip (’\n\r,’)

121
122 | # Handle the case when the string ends with a trailing comma
123 | if build_temp [ -2]:
124 | build_temp = build_temp [: -2]+ build_temp [ -1]

125
126 | try :
127 | nested_list = [ list ( map (float , innerList )) for innerList in
| json . loads ( build_temp )]
128 | except json . decoder . JSONDecodeError as e :
129 | print (" Error decoding JSON :", e)
130 | print (" Problematic data :", build_temp )

26

131 | return False

132
133 | for nested_item in nested_list :
134 | x_temp = (( nested_item [2] * cos ( nested_item [0] * ( pi / 180) ) *
| cos ( nested_item [1] * ( pi / 180) ) ) + 2000) /10
135 | y_temp = (( nested_item [2] * cos ( nested_item [0] * ( pi / 180) ) *
| sin ( nested_item [1] * ( pi / 180) ) ) + 2000) /10
136 | z_temp = (( nested_item [2] * sin ( nested_item [0] * ( pi / 180) )) +
| 2000) /10

137
138 | if x_temp < 1000 and y_temp < 1000:
139 | selected_dots . append ([ x_temp , y_temp , z_temp ])
140 | # print (" Selected dots :" , selected_dots )
141 | return selected_dots

142
143 | return False

144

145
146 | class ReadLine :
147 | def init ( self , s) :
148 | self . buf = bytearray ()
149 | self .s = s

150
151 | def readline ( self ) :
152 | i = self . buf . find (b"\n")
153 | if i >= 0:
154 | r = self . buf [: i +1]
155 | self . buf = self . buf [i +1:]
156 | return r. decode ("utf -8")

157
158 | while True :
159 | i = max (1 , min (2048 , self .s. in_waiting ) )
160 | data = self .s . read (i)
161 | i = data . find ( b"\n")
162 | if i >= 0:
163 | r = self . buf + data [: i +1]
164 | self . buf [0:] = data [i +1:]
165 | return r. decode ("utf -8")
166 | else :
167 | self . buf . extend ( data )

168
169 | ser = serial . Serial (’COM3 ’, 9600)
170 | rl = ReadLine ( ser )

171
172 | can_update = False
173 | list_for_3d = []

174
175 | while not printed :
176 | line = rl . readline ()
177 | # print (" Received :" , line )
178 | print_temp = str2list ( line )
179 | if print_temp != False :
180 | # print ( print_temp )
181 | if ( int ( print_temp [0][1]) == 0 and int ( print_temp [0][0]) == 0) :
182 | can_update = True
183 | if True :
184 | for i in print_temp :
185 | list_for_3d . append (i)
186 | print (len ( list_for_3d ) /50)
187 | if len ( list_for_3d ) >= 200*50:
188 | # plot_dots ( print_temp )
189 | # plot_lines ( print_temp )
190 | # print ( len ( list_for_3d ))
191 | # Specify the file path
192 | file_path = " example " + dt_string + ". txt "

193
194 | # Open the file in write mode
195 | with open ( file_path , ’w’) as file :

27

196 | # Write the text to the file
197 | file . write ( str ( list_for_3d ))

198
199 | print (f" Text saved to { file_path }")
200 | # print ( list_for_3d )
201 | plot_3d_surface ( list_for_3d )
202 | printed = True
Listing 6: Python Code for receiver

### 4.6.2 Code Explanation

Import Libraries

- import serial

– Provides serial communication capabilities.

- import json

– Used for parsing JSON data.

- from math import cos, sin, pi

– Provides trigonometric functions and the value of π.

- import matplotlib.pyplot as plt

– Used for plotting graphs.

- import numpy as np

– Provides support for large, multi-dimensional arrays and matrices.

- from mpl toolkits.mplot3d import Axes3D

– Enables 3D plotting.

- from datetime import datetime

– Provides date and time functionalities.

Datetime Initialization

1 | now = datetime . now ()
2 | dt_string = now . strftime ("%d/%m/%Y %H:%M:%S")

Initializes the current date and time and formats it as a string.

Plotting Functions

Defines functions for plotting different types of graphs:

- plot lines(coordinates): Plots lines connecting the coordinates.
- plot dots(coordinates): Plots dots at the coordinates.
- plot 3d surface(coordinates): Plots a 3D surface.
- plot 3d wireframe(coordinates): Plots a 3D wireframe.

28

String to List Conversion

1 | def str2list ( input_string ):
2 | ...

Converts the input string from the serial data into a list of coordinates.

ReadLine Class

1 | class ReadLine :
2 | def init ( self , s) :
3 | self . buf = bytearray ()
4 | self .s = s

5
6 | def readline ( self ) :
7 | ...

Class for reading lines from the serial port.

Main Code Block

1 | ser = serial . Serial (’COM3 ’, 9600)
2 | rl = ReadLine ( ser )
3 | can_update = False
4 | list_for_3d = []

5
6 | while not printed :
7 | line = rl . readline ()
8 | print_temp = str2list ( line )
9 | if print_temp != False :
10 | if ( int ( print_temp [0][1]) == 0 and int ( print_temp [0][0]) == 0) :
11 | can_update = True
12 | if True :
13 | for i in print_temp :
14 | list_for_3d . append (i)
15 | if len ( list_for_3d ) >= 200*50:
16 | file_path = " example " + dt_string + ". txt "
17 | with open ( file_path , ’w’) as file :
18 | file . write ( str ( list_for_3d ))
19 | plot_3d_surface ( list_for_3d )
20 | printed = True

Establishes a serial connection and continuously reads data. When sufficient data is collected, it saves the data to a file and plots a 3D surface.

29

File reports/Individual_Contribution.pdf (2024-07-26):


# Department of Electronic & Telecommunication

Engineering,
University of Moratuwa, Sri Lanka.

# 3D Mapping Device for Object Tracking Individual Contribution - Group B

## Submitted By:

210031H Amarasinghe A.A.W.L.R.

Submitted in partial fulfillment of the requirements for the module

# EN 2160 : Electronic Design Realization

23rd June 2024

EN2160 | Individual Contribution : Group B

When collaboration is concerned, most of the tasks were done collaboratively as it is essential for both members to have experience in all aspects of the design. However, when the responsibility for the completion of each task is concerned, some parts were taken by myself.

## 1 Circuit Design

Developing the circuit for the 3D scanner was the first task I engaged in. I had to consider various needs of our product, such as the best microcontroller for this task, the best IC for USB serial communication, how to connect two TOF sensors to the microcontroller, and choosing an I2C multiplexer for independent communication of the TOF sensors. Additionally, I had to ensure that the power supply design was robust enough to handle the varying loads and that all components were properly decoupled to minimize noise and interference. This required careful selection of capacitors and inductors to ensure stable operation. After finalizing the circuit and components, I ordered the components from Mouser in Texas, USA, and LCSC Electronics in Shenzhen, China. This step was crucial to ensure that all parts were available and matched the design specifications.

## 2 PCB Design

Designing the PCB was done by me. I had to consider the thermal management of the components and the signal flow of the circuit. I tried to keep the routing paths as short as possible for the smooth operation of the PCB. I followed the IEEE guidelines and the instructions given by the lecturer when designing the PCB. Furthermore, I had to design the layout to minimize electromagnetic interference (EMI) and ensure proper grounding. This involved creating a 2-layer PCB with dedicated power and ground planes. After finalizing the PCB design, I sent the design files to JLCPCB in China for manufacturing. This involved generating the Gerber files and Bill of Materials (BOM), ensuring all files were correctly formatted and included all necessary information for the manufacturing process. I chose JLCPCB due to their high-quality manufacturing standards and quick turnaround times, which were essential for keeping our project on schedule.

## 3 Visualizer Programming

In the 3D mapper, we get distance data from the TOF sensors and send it to the computer for processing. I created a 3D mesh with the distance data using Python libraries. Then, using 3D Delaunay triangulation, I was able to make the 3D visualizer. The visualizer needed to be efficient and capable of handling large datasets in real-time, so I optimized the code for performance. Additionally, I added features such as interactive zoom, pan, and rotate, as well as the ability to save and load 3D models. This made the visualizer a useful tool for both development and demonstration purposes.

## 4 Document Preparation

We had to prepare two main documents: the design document and the design methodology report. I prepared them using LaTeX according to the required sections. The design document detailed the specifications, schematics, and design choices for the 3D scanner, while the design methodology report described the process and rationale behind our decisions. I ensured that both documents were well-structured and free of grammatical errors, and included diagrams and figures to illustrate key points. Additionally, I incorporated feedback from my collaborators to refine and improve the documents.

1

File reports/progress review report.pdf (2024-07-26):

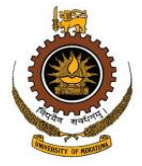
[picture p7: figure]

# Department of Electronic & Telecommunication

Engineering,
University of Moratuwa, Sri Lanka.

# 3D Mapping Device for Object Tracking Progress Review Report

## Submitted By:

210031H | Amarasinghe A.A.W.L.R.
210728C | Wijewickrama W.K.D.D.D

Submitted in partial fulfillment of the requirements for the module

# EN2160 : Electronic Design Realization

15th March 2024

EN2160 | Progress Review Report: Group B

## Contents

1 Companies in the 3D Mapping Field | 2
2 Researches Regarding 3D Mapping Technologies | 3
2.1 Research on 3D Digital Map System and Key Technology - Zhao Zhongyuan . . . . | 3
2.3 A Survey of 3D Object Detection Algorithms for Intelligent Vehicles Development . | 4
3 YouTube Videos Regarding 3D Mapping Technologies | 5
3.1 3D Time-of-Flight (ToF) camera for accurate 3D depth imaging — e-con Systems . | 5
4 Project Plan | 6
5 Stakeholder Map | 7
6 Conclusion | 7

1

## 1 Companies in the 3D Mapping Field

1. Microsoft: Microsoft has developed the Microsoft Kinect sensor, which utilizes TOF technology for depth sensing. While the Kinect was initially popular in gaming, its applications have extended to various industries, including robotics, healthcare, and augmented reality.

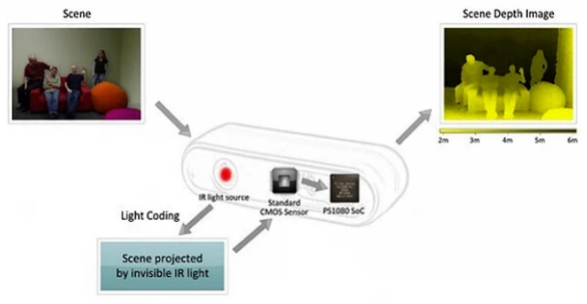
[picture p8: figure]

Figure 1: Kinect Sensor

2. Intel: Intel has been actively involved in developing TOF sensors for depth sensing applications. Their RealSense series includes TOF cameras suitable for various industrial and consumer applications, including robotics, augmented reality, and 3D scanning.

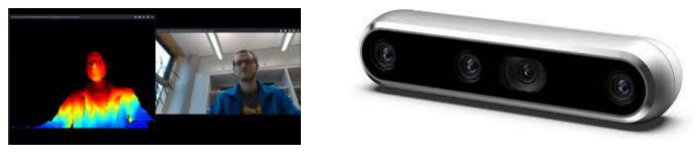
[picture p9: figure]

Figure 2: RealSense

3. Velodyne: While primarily known for their lidar sensors for autonomous vehicles, Velodyne has also been exploring TOF technology for short-range applications. They have developed sensors capable of accurate distance measurement and object detection.

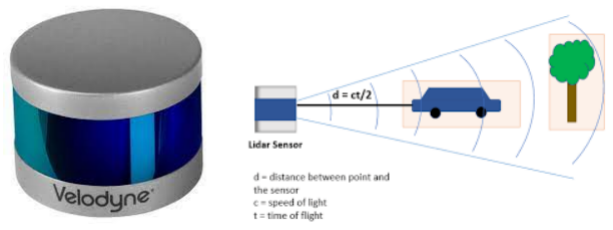
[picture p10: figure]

Figure 3: Velodyne

2

## 2 Researches Regarding 3D Mapping Technologies

### 2.1 Research on 3D Digital Map System and Key Technology - Zhao

Zhongyuan

This paper discusses the concept, characteristics, and key technologies associated with 3D digital maps, focusing on the case study of the Wuhan 3D digital map system.

Concepts and Characteristics:

- 3D digital maps represent a continuous 3D digital model of a city, serving as the core of 3D digital city construction.
- They integrate various elements such as natural topography, environment, roads, buildings, and infrastructure into a seamless mosaic under a coordinate system.
- These maps leverage technologies like GIS, RS, network, multimedia, and VR to create a multi-dimensional digital city information platform.

Characteristics of 3D Digital Map Systems:

- They create a virtual space environment of the real city, enabling dynamic interactive browsing, spatial analysis, and simulation of large amounts of data.
- They support geographic synergies in network environments, allowing seamless management of urban space and multi-user concurrent access.
- They serve as a 3D space basic platform for city management, providing macro information, and detailed data for various city management activities.

Key Technologies:

- Advanced technologies such as 3DGIS, VR, data compression, computer, and network technologies are employed.

2.2 2D and 3D Object Detection Algorithms from Images: A Survey

This survey provides an overview of the current state and trends in object detection research, focusing on both 2D and 3D object detection algorithms.

Object Detection Overview:

- Object detection, a crucial branch of computer vision, locates and classifies objects in images, encompassing tasks such as object recognition and localization.
- Traditional object detection algorithms relied on hand-designed methods for feature extraction and suffered from limitations such as slow speed, low accuracy, and high computational overhead.

Transition to Deep Learning:

- Deep convolutional neural networks (CNNs) revolutionized object detection by efficiently extracting features from images, leading to significant improvements in speed and accuracy.
- The rise of CNN-based models, such as AlexNet, and Swin Transformer, replaced traditional algorithms and became the mainstream in object detection research.

3

Recent Advances:

- Recent advancements include the adoption of Transformer models, such as ViT, in object detection, offering dynamic parameter learning mechanisms and improved adaptability to large datasets.
- These developments have sparked research into incorporating Transformers into object detection frameworks as backbone or neck components, further enhancing performance.

Transition to 3D Object Detection:

- While 2D object detection focuses on regressing 2D bounding boxes, the practical needs of real-world applications require 3D object detection to predict detailed information about an object’s 3D size, coordinates, speed, and orientation.
- However, transitioning from 2D to 3D object detection presents challenges such as the lack of geometric constraints, and handling multidimensional data.

Importance of 3D Object Detection:

- Despite these challenges, 3D object detection algorithms have gained importance in both industrial and academic communities due to their potential applications in unmanned vehicles, smart robots, and real-time traffic monitoring.

### 2.3 A Survey of 3D Object Detection Algorithms for Intelligent Vehicles

Development

This survey highlights the importance of 3D object detection in intelligent driving technology, particularly for the development of safe and reliable self-driving cars.

Background:

- Despite the significant advancements in 2D object detection, particularly in computer vision applications, there are limitations when it comes to intelligent driving.
- The safety and reliability of self-driving cars require the ability to detect 3D models of objects in their surroundings to perceive real driving situations accurately.

Development of 3D Object Detection:

- The paper systematically surveys the development of 3D object detection methods applied to intelligent driving technology.
- It analyzes the shortcomings of existing 3D detection algorithms and discusses future development directions in this field, emphasizing the importance of accurate environment perception for reducing traffic accidents.

Hardware Preparations for Intelligent Driving:

- The paper discusses the technologies demanded by intelligent driving, including sensors, highprecision maps, Internet of Vehicles (IoV), and high-performance chips.
- It provides an overview of the development levels of autonomous driving, highlighting the progression from Level 0 (fully manual) to Level 5 (fully autonomous).

4

## 3 YouTube Videos Regarding 3D Mapping Technologies

3.1 3D Time-of-Flight (ToF) camera for accurate 3D depth imaging — e-con Systems

- Link: https://www.youtube.com/watch?v=8JIBTZCXkHw
- Description: DepthVista is a 3D Time-of-Flight (ToF) camera designed by e-con Systems for accurate 3D depth imaging to help Autonomous Mobile Robots (AMRs) and Automated Guided Vehicles (AGVs) with safer navigation.
- Features:

– Streams 3D depth data & RGB data in single frame: Enables both obstacle detection & object recognition/identification with one camera.
– Uses VCSEL of 850nm: Safer for human eyes and can operate even in absolute darkness. – High speed & high resolution 640×480 @ 30 fps: Allows AMRs and AGVs to perceive their environment and plan their paths optimally, and safely complete their tasks.
– Onboard depth image processing: Provides ready-to-use depth data from the camera itself thereby reducing the computational load on the host.
- Target Applications:

– Autonomous Mobile Robots (AMRs)
– Autonomous Guided Vehicles (AGVs) – People counting in retail analytics
– Patient care / Patient Monitoring
– 3D Face recognition for anti-spoofing
– Robotic arms

### 3.2 Distance linear image sensor / Object detection [TOF]

- Link: https://www.youtube.com/watch?v=Y0P-fXSTbzQ
- Description: The distance image sensors are designed to measure the distance to an object using the TOF method. This video demonstrates distance measurement to a target object ahead (human) using a unit equipped with a distance linear image sensor and light source. The output waveform, matched to the target object’s position and movement, is shown.

### 3.3 Visionary-T Mini: 3D ToF camera solving industrial applications

- Link: https://www.youtube.com/watch?v=n6u2HQ5R2w8
- Description: The Visionary-T Mini ensures more efficiency in industrial settings wherever reliable 3D depth values for dynamic processes are needed.
- Fields of Applications:

– Object detection
– Navigation
– Palletizing and depalletizing
– Measurement and volume detection – Positioning
– Gesture control
– Area monitoring

5

## 4 Project Plan

1. Planning and Research:
- Define objectives and requirements.
- Research components and potential challenges.
2. Component Procurement:
- Purchase necessary components.
- Ensure compatibility and quality.
3. Sensor Calibration:
- Develop calibration algorithms.
- Test and refine calibration process.
4. Hardware Development:
- Assemble hardware components.
- Optimize layout and connections.
- Conduct preliminary testing.
5. Power Optimization:
- Implement power-saving techniques.
- Validate efficiency through testing.
6. Software Development:
- Develop software utility for real-time monitoring and object detection.
- Design user-friendly interface.
- Integrate with hardware.
7. Testing and Validation:
- Conduct thorough testing.
- Validate accuracy and reliability.
- Test object tracking capabilities.
8. Documentation and Finalization:
- Document project details.
- Address any remaining issues.
9. Presentation and Deployment:
- Present project outcomes.
- Gather feedback.
- Plan for deployment or further development.

6

## 5 Stakeholder Map

- The stakeholder map diagram delineates various stakeholders involved in a project, categorized based on their levels of interest and influence. Through a quadrant-based approach, stakeholders are strategically positioned according to their degree of engagement and impact on project outcomes.
- This systematic classification facilitates stakeholder management by enabling the anticipation of stakeholders’ needs, ensuring thorough engagement with key stakeholders, and maintaining regular communication channels with those deemed most critical.
- By aligning stakeholder engagement strategies with their respective levels of interest and influence, project stakeholders can be effectively managed to optimize project outcomes.

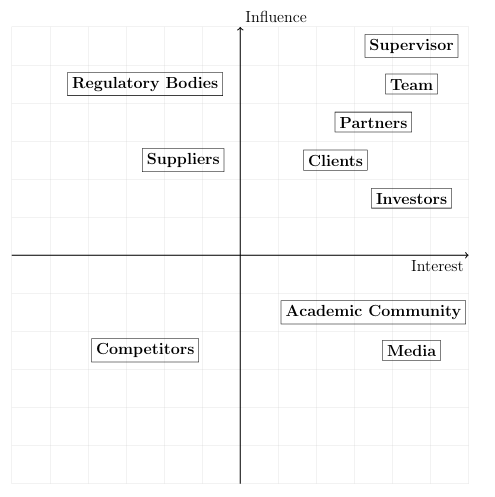
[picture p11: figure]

Figure 4: Stakeholder Map

## 6 Conclusion

In conclusion, the ”3D Mapping Device Project” has made significant strides in applying engineering principles, mathematics, science, and hands-on skills to develop a sophisticated and versatile scanning system. Over the course of its development, the project team has demonstrated a deep understanding of various engineering concepts and methodologies, ensuring that the device meets industry standards while also addressing broader societal needs.

Ultimately, the stakeholder map highlights the importance of engaging and managing various stakeholders, including supervisors, team members, investors, clients, partners, regulatory bodies, suppliers, competitors, media, academic community, and users. The project could greatly improve efficiency, accuracy, and cost-effectiveness across different industries, making it an exciting and promising initiative.

7

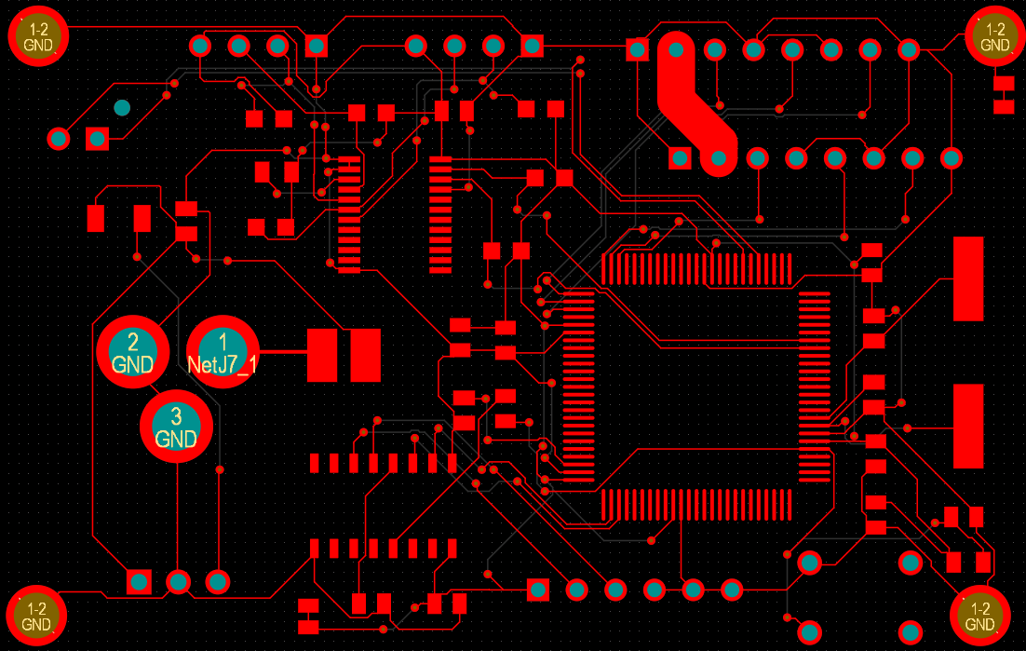
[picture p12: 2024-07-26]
PCB design/top layer.png

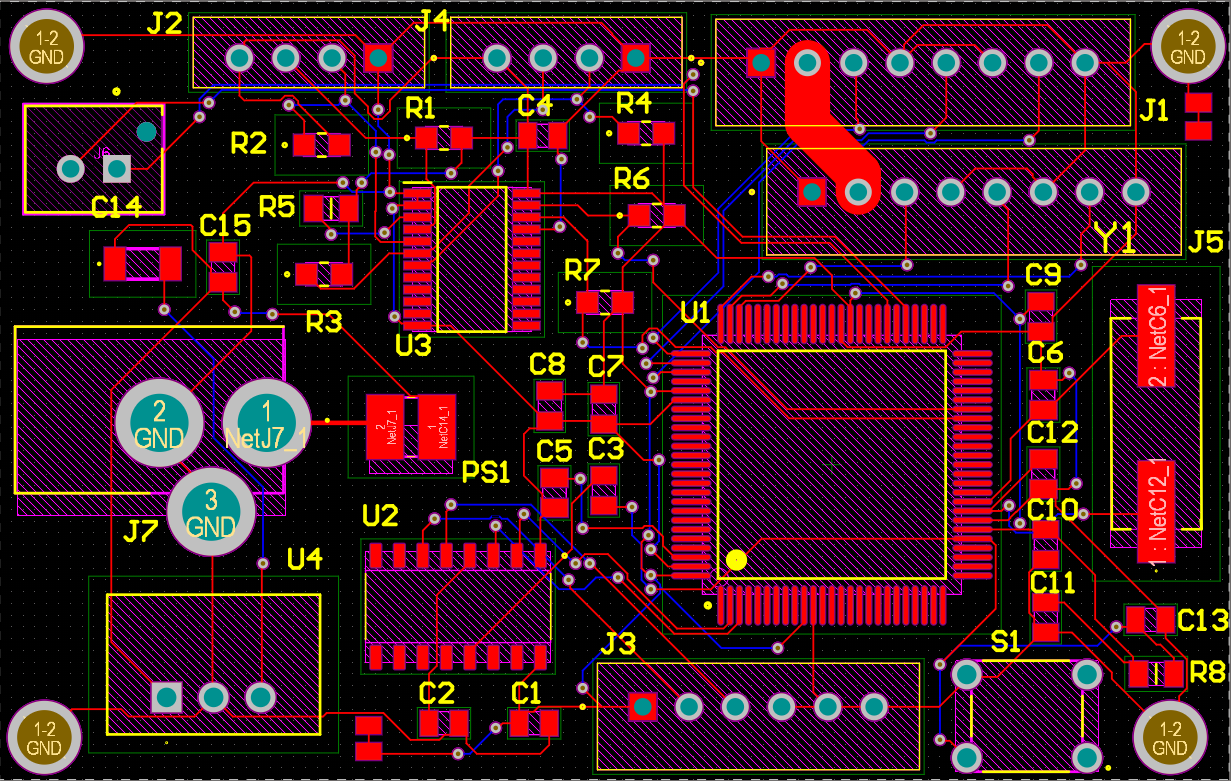
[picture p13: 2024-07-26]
PCB design/PCB.png

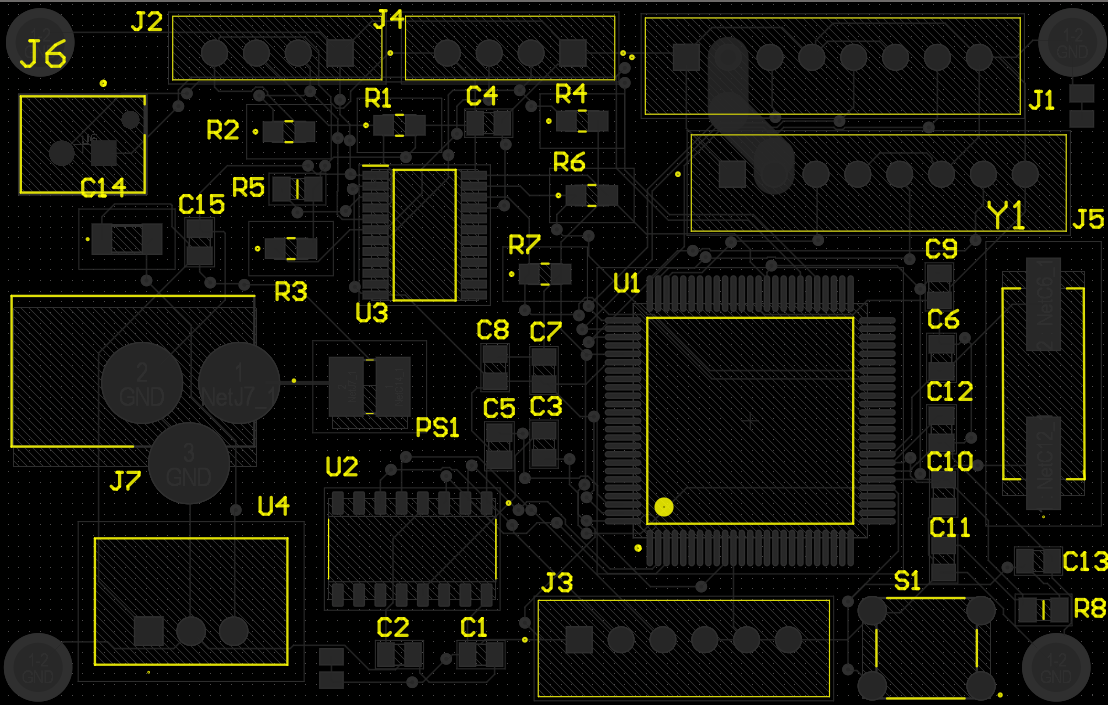
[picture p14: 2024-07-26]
PCB design/Overlay layer.png

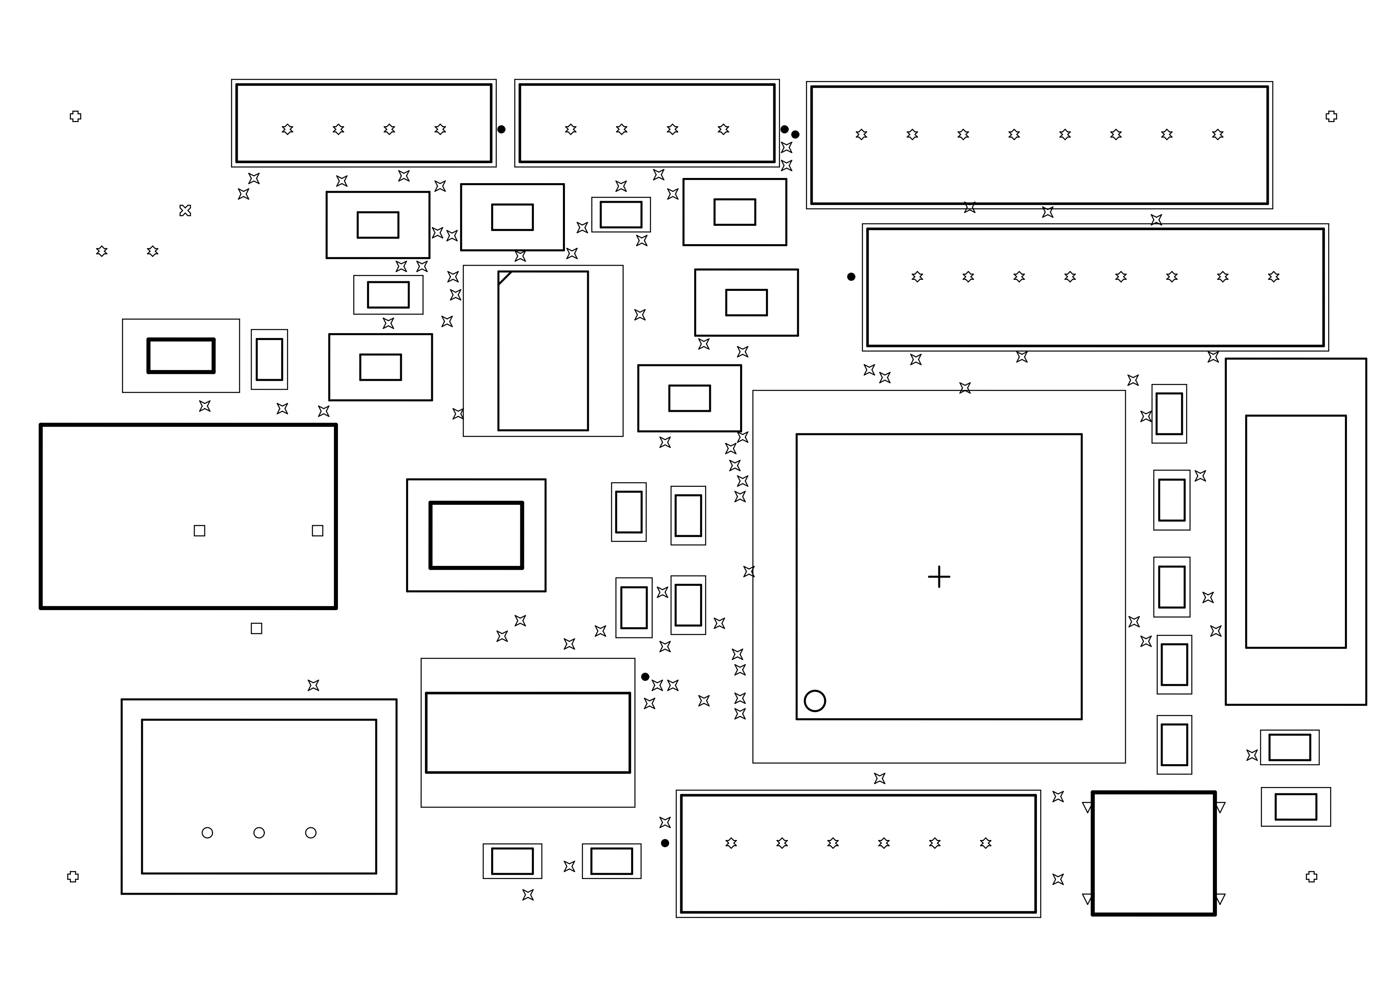
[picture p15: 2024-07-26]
PCB design/drill.jpg

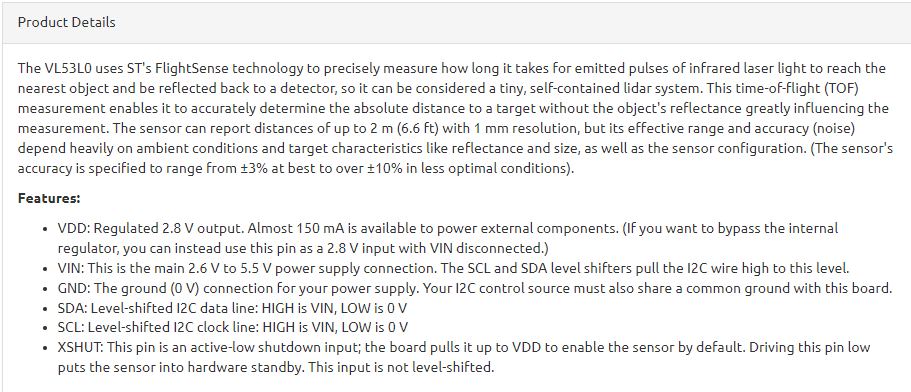
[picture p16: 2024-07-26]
data sheets/TOF.png

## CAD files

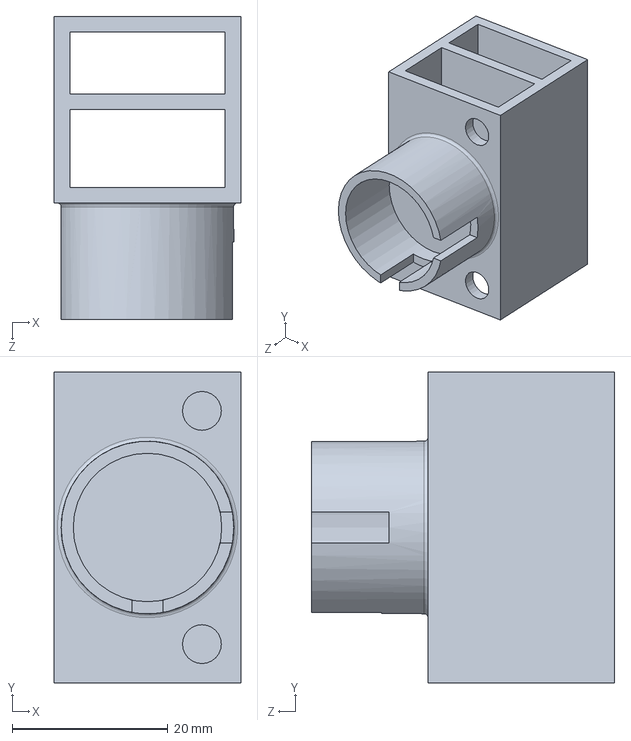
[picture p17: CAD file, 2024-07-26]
solidworks design/revolve.SLDPRT
24.0 x 40.0 x 39.0 mm

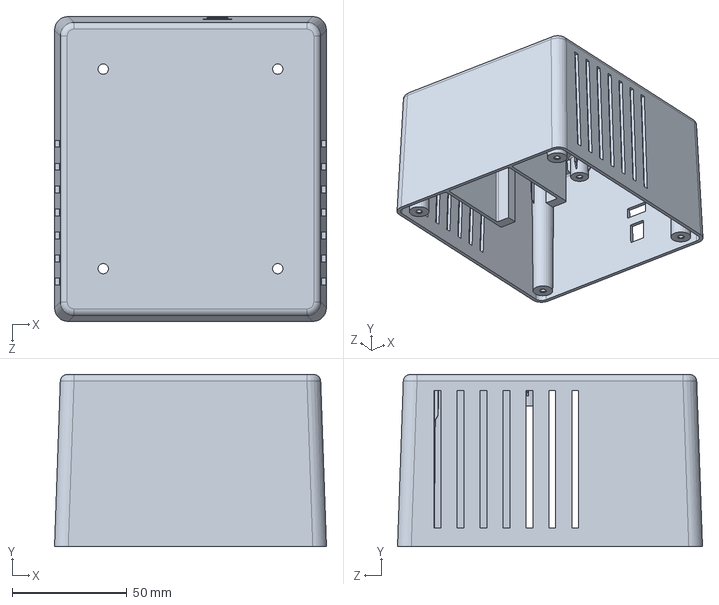
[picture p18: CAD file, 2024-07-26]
solidworks design/top.SLDPRT
118.6 x 75.0 x 133.0 mm

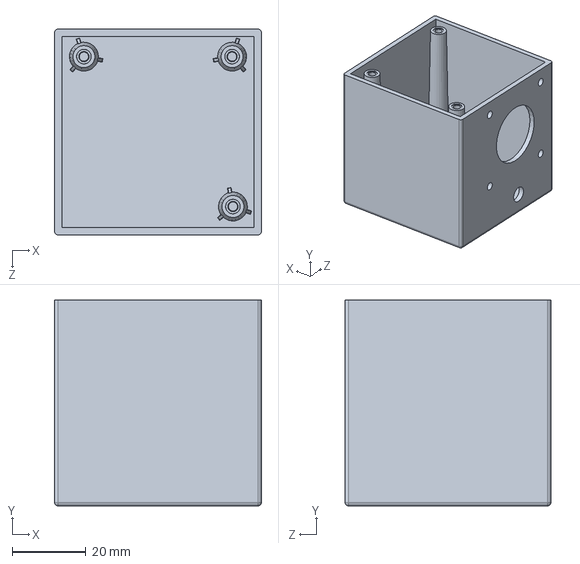
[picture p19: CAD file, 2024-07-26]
solidworks design/Toptop.SLDPRT
56.3 x 56.0 x 56.0 mm

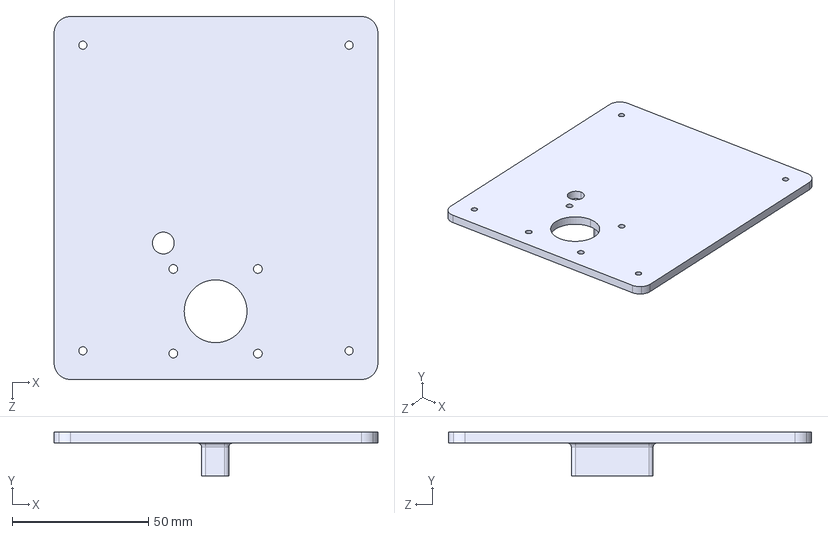
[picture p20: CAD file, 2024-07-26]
solidworks design/Bottom.STEP
118.6 x 16.0 x 133.0 mm

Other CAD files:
solidworks design/Topbottom.SLDPRT
solidworks design/Bottom.SLDPRT
solidworks design/Bottom.STL
solidworks design/Topbottom.STL
solidworks design/Toptop.STL
solidworks design/revolve.STL
solidworks design/top.STL

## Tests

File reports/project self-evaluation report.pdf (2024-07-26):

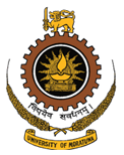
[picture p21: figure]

Department of Electronic and Telecommunication Engineering University of Moratuwa

Electronic Design Realization

210728C - Wijewickrama W.K.D.D.D.

210031H - Amarasinghe A.A.W.L.R.

# 3D Surround Scanner Project Report

## Application of Engineering Principles

During the last three semesters, we have learned various engineering principles that we applied in our project:

- Design Principles: We followed a systematic approach to design our 3D scanner. We started with a clear definition of the problem, identified the requirements, and then moved on to the design and testing phases. We also considered factors such as functionality, aesthetics, and user-friendliness in our design.
- Analytics: We used analytical methods to understand and interpret the data collected by our scanner. This helped us to make informed decisions during the design and testing phases.
- Enclosure and PCB Designing Principles: We designed a compact and robust enclosure for our scanner. We also designed a Printed Circuit Board (PCB) that houses all the electronic components of our scanner.

## Application of Mathematics and Science

We applied various mathematical and scientific concepts that we learned during our A/L and the last three semesters:

- Linear Algebra: We used linear algebra for processing the raw data collected by our scanner into a 3D image.
- Signal Processing: We used signal processing techniques to filter out noise and extract the correct data from the raw data collected by our scanner.
- Programming Skills: We used our programming skills to write the software that controls our scanner and renders the 3D image from the processed data.

- Cartesian Geometry: We used concepts from Cartesian geometry to map the data points collected by our scanner into a 3D space.

## Hands-On Skills

We applied various hands-on skills that we learned during the last three semesters:

- PCB Design, Soldering, and Testing: We designed the PCB for our scanner, soldered the components onto it, and tested it to ensure it works as expected.
- Enclosure Design: We designed a robust and user-friendly enclosure for our scanner.
- Testing and Debugging: We thoroughly tested our scanner and debugged any issues that we encountered.

## Applicability of the Project for Solving an Industrial Problem in Sri Lanka

The 3D scanner project has versatile applications in Sri Lanka's industries:

- Warehouse Management: Improves inventory tracking for better supply chain management.
- Construction: Facilitates site surveying, BIM, and construction progress monitoring for efficiency.
- Heritage Preservation: Aids in documenting and preserving cultural sites and artifacts.
- Disaster Management: Assists in terrain mapping and infrastructure assessment for better resilience.

## Cost of Main Components

The rough prices of our main components are as follows.

- 2 Nemma 17 stepper motors- Rs.3000
- Atmega 328 microcontroller- Rs.1500
- Time-of-Flight (ToF) sensor-Rs.1000
- A4988 Stepper Motor Driver-Rs.500

We use industry-level cost-effective components. The total cost of these components is within our budget.

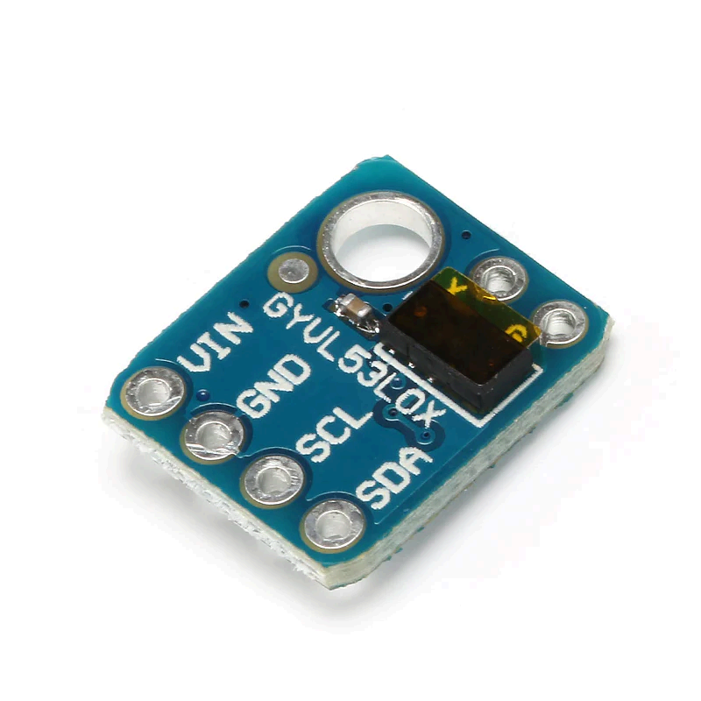
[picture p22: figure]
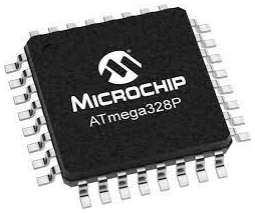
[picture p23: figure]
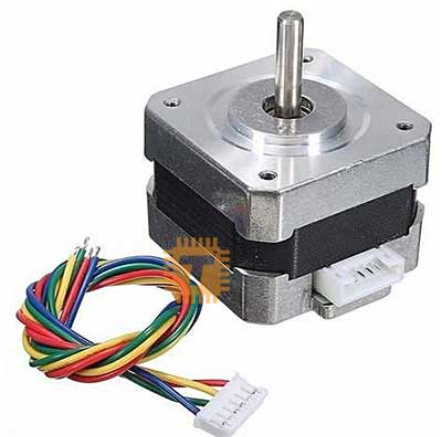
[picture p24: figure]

Fig 1 : Nema 17 Stepper Motor | Fig 2 : Atmega 328P Microcontroller | Fig 3 : Time of Flight Sensor

## Suitability of the Project to Achieve the Learning Outcomes of the Electronic Design Realization Module

Our project aligns well with the learning outcomes of the Electronic Design Realization module. We applied various engineering principles, mathematical and scientific concepts, and hands-on skills that we learned during the module. We also learned how to work as a team, manage a project, and communicate our ideas effectively. Overall, this project provided us with a valuable opportunity to apply what we learned in the module to a real-world problem.

### 1.Identify a suitable design model for a given problem:

The report indicates a systematic approach to problem definition, requirement identification, and design. This demonstrates the application of design principles to address a specific problem, which aligns with this learning outcome.

### 2.Design testable PCBs complying with industry standards:

The project involves designing a Printed Circuit Board (PCB) to house electronic components. Although the report doesn't explicitly mention compliance with industry standards, the inclusion of industry-level cost-effective components suggests adherence to certain standards and practices.

### 3.Explain testing methodologies used in electronic manufacturing:

The report mentions thorough testing and debugging of the scanner, indicating an understanding and application of testing methodologies in electronic manufacturing.

### 4.Design product enclosures complying with industry standards:

The project includes designing a robust and user-friendly enclosure, which suggests consideration for industry standards related to product enclosure design.

### 5.Prepare proper documentation for electronic design:

While the report doesn't provide explicit details about documentation, the comprehensive description of the project's development process and components used implies a level of documentation suitable for electronic design projects.

### 6.Apply the knowledge gained to a commercial design project resulting in a working prototype:

The project involves the application of engineering principles, mathematical concepts, and hands-on skills to develop a working prototype of a 3D scanner. This aligns closely with the objective of applying knowledge to a commercial design project.

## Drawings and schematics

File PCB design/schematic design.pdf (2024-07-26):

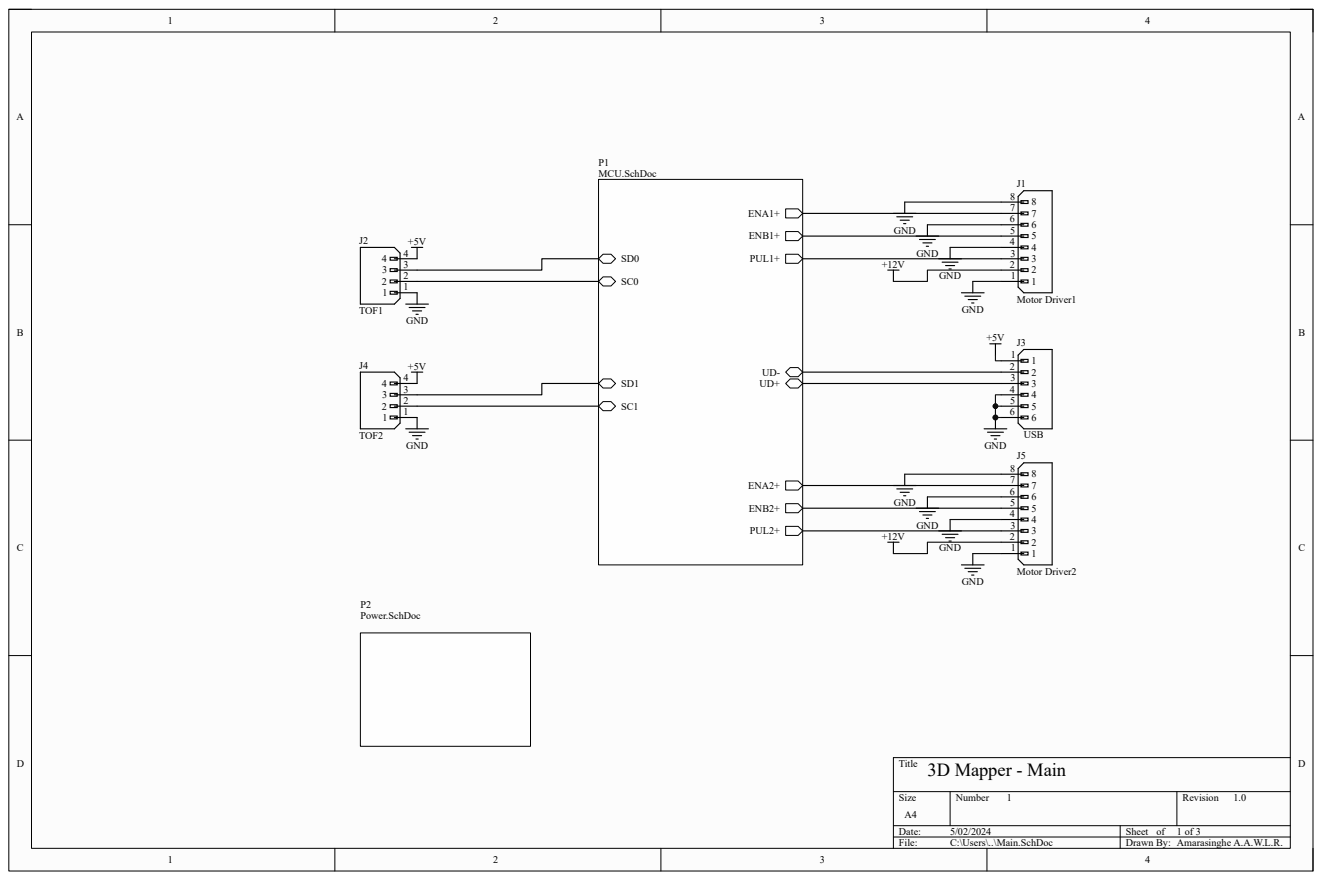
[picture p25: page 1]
Title; Size; Number; Revision; Date:; Sheet of; File:; C:\Users\..\Main.SchDoc; Drawn By:; ENA1+; PUL1+; ENB1+; ENA2+; ENB2+; PUL2+; P1 MCU.SchDoc; Motor Driver1; GND; TOF2; Amarasinghe A.A.W.L.R.; 3D Mapper - Main; TOF1; Motor Driver2; P2 Power.SchDoc; USB

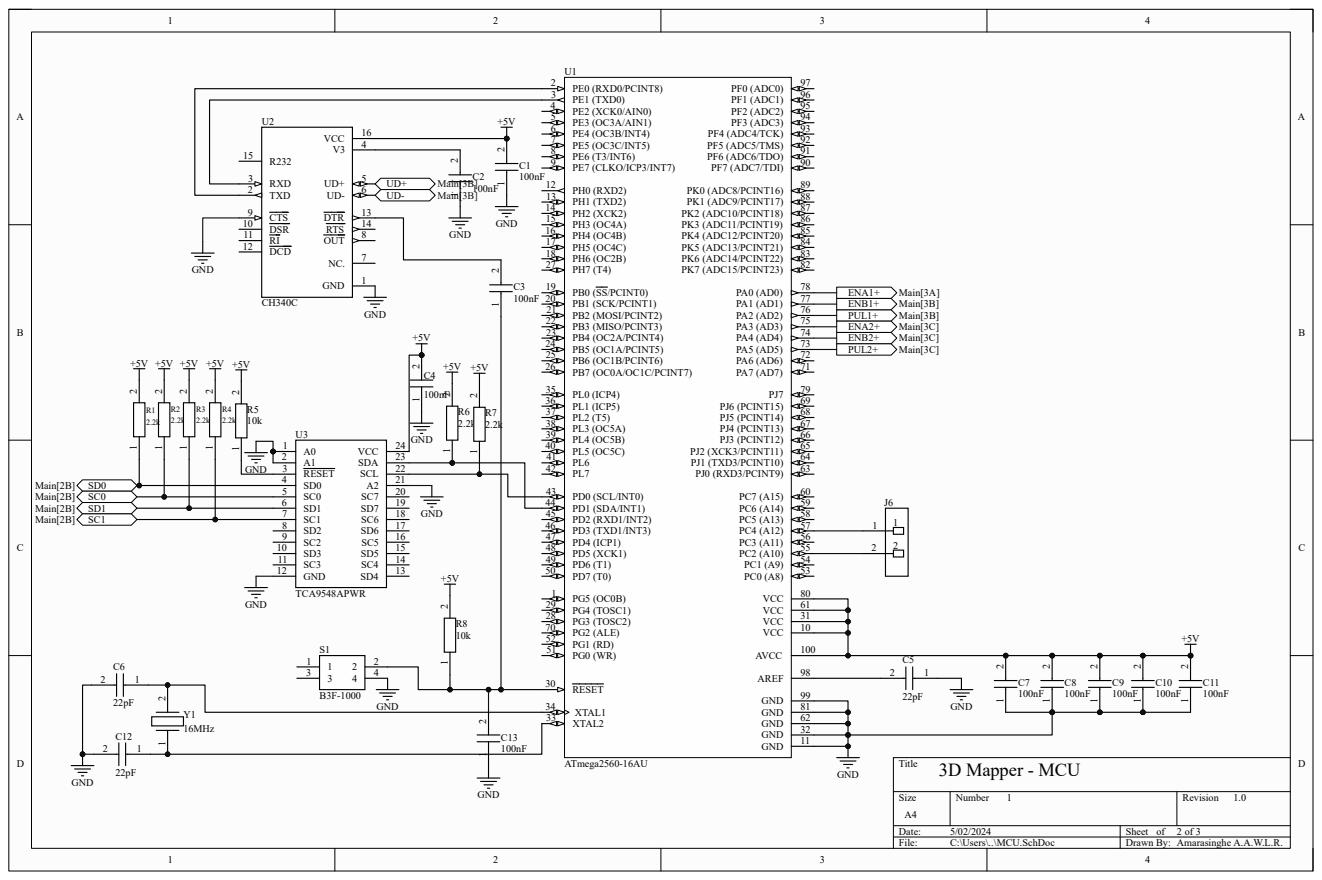
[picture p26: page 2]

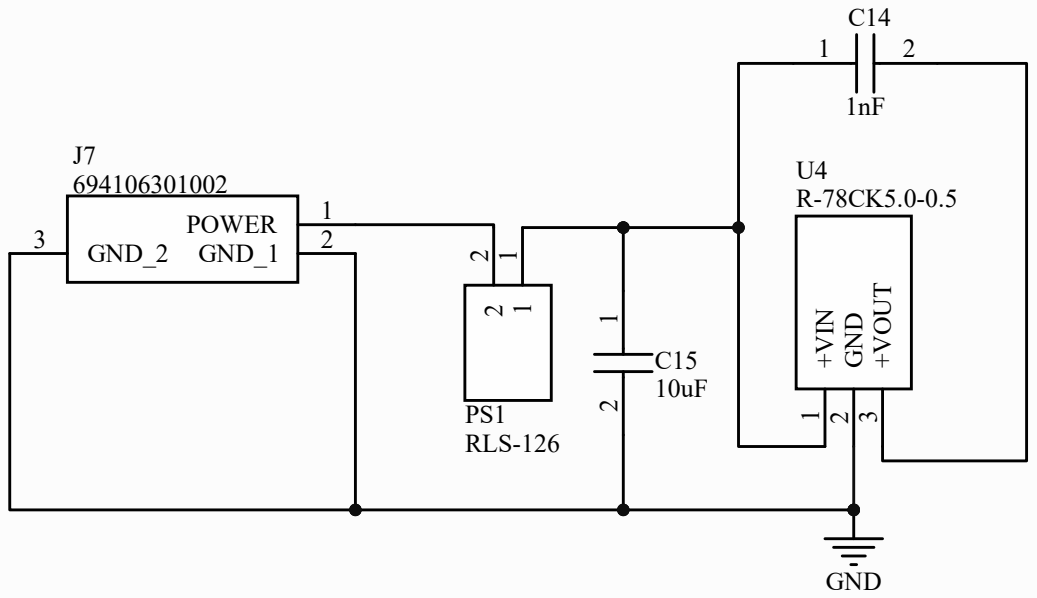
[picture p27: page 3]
Title; Size; Number; Revision; File:; C:\Users\..\Power.SchDoc; Drawn By:; 1 GND; GND ¹; PS1 RLS-126; POWER; GND_1; 2 GND_2 3

2 +VOUT
3D Mapper - Power ⁺VIN

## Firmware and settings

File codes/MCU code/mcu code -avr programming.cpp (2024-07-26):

#include <avr/io.h>
#include <util/delay.h>
#include <avr/interrupt.h>
#include "VL53L0X.h"

#define STEP_PIN_1 24
#define DIR_PIN_1 23
#define ENA_PIN_1 22

#define STEP_PIN_2 27
#define DIR_PIN_2 26
#define ENA_PIN_2 25

#define XY_REV 200
#define XZ_REV 50

#define ANGLE_INCREMENT 1.8

#define F_CPU 16000000UL // Assuming a 16 MHz clock
#define BAUD 9600
#define MYUBRR F_CPU/16/BAUD-1

#define F_SCL 100000UL // SCL frequency
#define Prescaler 1
#define TWBR_val ((((F_CPU / F_SCL) / Prescaler) - 16) / 2)

float measurements[XZ_REV][3];

void uart_init(unsigned int ubrr) {
  // Set baud rate
  UBRR0H = (unsigned char)(ubrr >> 8);
  UBRR0L = (unsigned char)ubrr;
  // Enable receiver and transmitter
  UCSR0B = (1 << RXEN0) | (1 << TXEN0);
  // Set frame format: 8 data bits, 1 stop bit
  UCSR0C = (1 << UCSZ01) | (1 << UCSZ00);
}

void uart_transmit(unsigned char data) {
  // Wait for empty transmit buffer
  while (!(UCSR0A & (1 << UDRE0)));
  // Put data into buffer, sends the data
  UDR0 = data;
}

void uart_print(const char *str) {
  while (*str) {
    uart_transmit(*str++);
  }
}

void i2c_init(void) {
  TWSR = 0x00;
  TWBR = (uint8_t)TWBR_val;
}

void i2c_start(void) {
  TWCR = (1 << TWINT) | (1 << TWSTA) | (1 << TWEN);
  while (!(TWCR & (1 << TWINT)));
}

void i2c_stop(void) {
  TWCR = (1 << TWINT) | (1 << TWSTO) | (1 << TWEN);
  while (TWCR & (1 << TWSTO));
}

void i2c_write(uint8_t data) {
  TWDR = data;
  TWCR = (1 << TWINT) | (1 << TWEN);
  while (!(TWCR & (1 << TWINT)));
}

uint8_t i2c_read_ack(void) {
  TWCR = (1 << TWINT) | (1 << TWEN) | (1 << TWEA);
  while (!(TWCR & (1 << TWINT)));
  return TWDR;
}

uint8_t i2c_read_nack(void) {
  TWCR = (1 << TWINT) | (1 << TWEN);
  while (!(TWCR & (1 << TWINT)));
  return TWDR;
}

void tof(uint8_t bus) {
  i2c_start();
  i2c_write(0x70 << 1); // TCA9548A address is 0x70
  i2c_write(1 << bus);  // send byte to select bus
  i2c_stop();
}

void setup() {
  uart_init(MYUBRR);  // Initialize the UART
  i2c_init();         // Initialize I2C

  tof(1);

  // Set pin modes using direct port manipulation
  DDRB |= (1 << DDB0) | (1 << DDB1) | (1 << DDB2); // STEP_PIN_1, DIR_PIN_1, ENA_PIN_1
  DDRB |= (1 << DDB3) | (1 << DDB4) | (1 << DDB5); // STEP_PIN_2, DIR_PIN_2, ENA_PIN_2

  // Enable pins
  PORTB &= ~(1 << PORTB2); // ENA_PIN_1 LOW
  PORTB &= ~(1 << PORTB5); // ENA_PIN_2 LOW

  // Move to the starting position
  PORTB &= ~(1 << PORTB4); // DIR_PIN_2 LOW
  for (int i = 0; i < XZ_REV / 2; i++) {
    PORTB |= (1 << PORTB3); // STEP_PIN_2 HIGH
    PORTB &= ~(1 << PORTB3); // STEP_PIN_2 LOW
    delayMicroseconds(50);
  }

  uart_print("VL53L0X test with Stepper Motor\n");
}

void loop() {
  for (int i = 0; i < XY_REV; i++) {
    if (i % 2 == 0) {
      PORTB |= (1 << PORTB4); // DIR_PIN_2 HIGH
    } else {
      PORTB &= ~(1 << PORTB4); // DIR_PIN_2 LOW
    }
    for (int j = 0; j < XZ_REV; j++) {
      i2c_start();
      i2c_write(0x29 << 1); // VL53L0X address
      i2c_write(0x00); // Register to read
      i2c_start();
      i2c_write((0x29 << 1) | 1); // Read mode
      uint8_t range = i2c_read_nack();
      i2c_stop();

      if (i % 2 == 0) {
        if (range != 255) {  // Check if range is valid
          measurements[j][0] = j * ANGLE_INCREMENT - 45;
          measurements[j][1] = i * ANGLE_INCREMENT;
          measurements[j][2] = range;
        } else {
          measurements[j][0] = j * ANGLE_INCREMENT - 45;
          measurements[j][1] = i * ANGLE_INCREMENT;
          measurements[j][2] = 10000;
        }
      } else {
        if (range != 255) {  // Check if range is valid
          measurements[XZ_REV - j - 1][0] = j * ANGLE_INCREMENT - 45;
          measurements[XZ_REV - j - 1][1] = i * ANGLE_INCREMENT;
          measurements[XZ_REV - j - 1][2] = range;
        } else {
          measurements[XZ_REV - j - 1][0] = j * ANGLE_INCREMENT - 45;
          measurements[XZ_REV - j - 1][1] = i * ANGLE_INCREMENT;
          measurements[XZ_REV - j - 1][2] = 10000;
        }
      }
      PORTB |= (1 << PORTB3); // STEP_PIN_2 HIGH
      PORTB &= ~(1 << PORTB3); // STEP_PIN_2 LOW
    }
    uart_print("aaa[");
    for (int k = 0; k < XZ_REV; k++) {
      uart_transmit('[');
      uart_print(measurements[k][0]);
      uart_transmit(',');
      uart_print(measurements[k][1]);
      uart_transmit(',');
      uart_print(measurements[k][2]);
      uart_transmit(']');
      if (k < XZ_REV - 1) uart_transmit(',');
    }
    uart_print("]\n");
    PORTB |= (1 << PORTB0); // STEP_PIN_1 HIGH
    PORTB &= ~(1 << PORTB0); // STEP_PIN_1 LOW
  }
}
